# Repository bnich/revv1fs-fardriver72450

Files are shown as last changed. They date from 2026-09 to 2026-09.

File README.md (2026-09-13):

# FarDriver ND72450 under-seat mount — Ride1Up REVV1 FS

A pair of printed brackets that carry a **FarDriver ND72450** controller under the seat of a
**Ride1Up REVV1 FS**, bolting to the frame's existing rail lugs. No frame modification, no drilling,
no welding.

**Printed and in service.**

<p align="center">
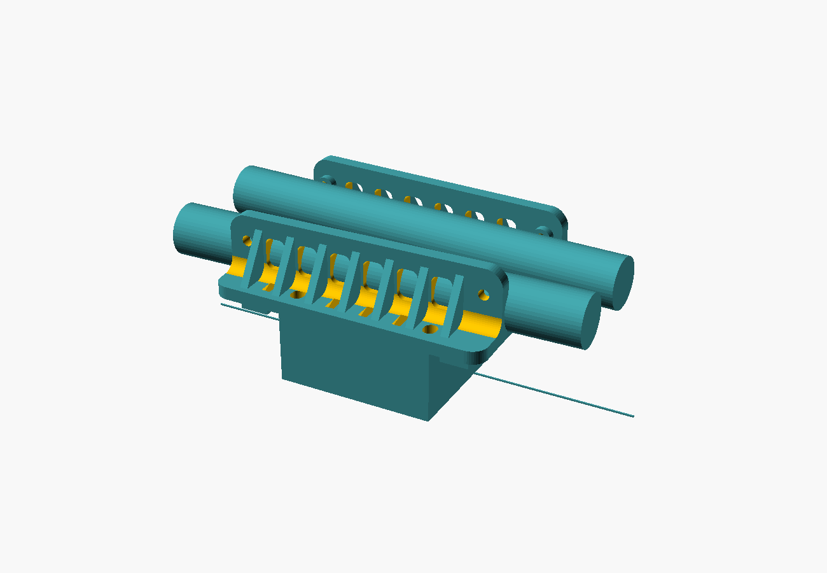
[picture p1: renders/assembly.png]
Isometric render of the pair of brackets spanning both frame rails, with the FarDriver controller slung beneath, showing the ribbed shelves and louvred vertical panels
  
</p>

The controller sits centred across the bike, spanning both rails and bolted to both brackets. Each
bracket carries roughly half the weight close in to its own rail, and the load is carried mostly in
**shear** rather than as a moment.

---

## What you get

| Part | Size | |
|---|---|---|
| `bracket_left` | 215 × 50.3 × 55 mm | one per rail |
| `bracket_right` | 215 × 50.3 × 55 mm | ⚠️ **a mirror image, not the same part again** |
| `brackets_plate` | 215 × 118 × 50.3 mm | both, laid down on one plate |
| `gauge` | 219.5 × 44 × 4 mm | print this **first** — see below |

<p align="center">
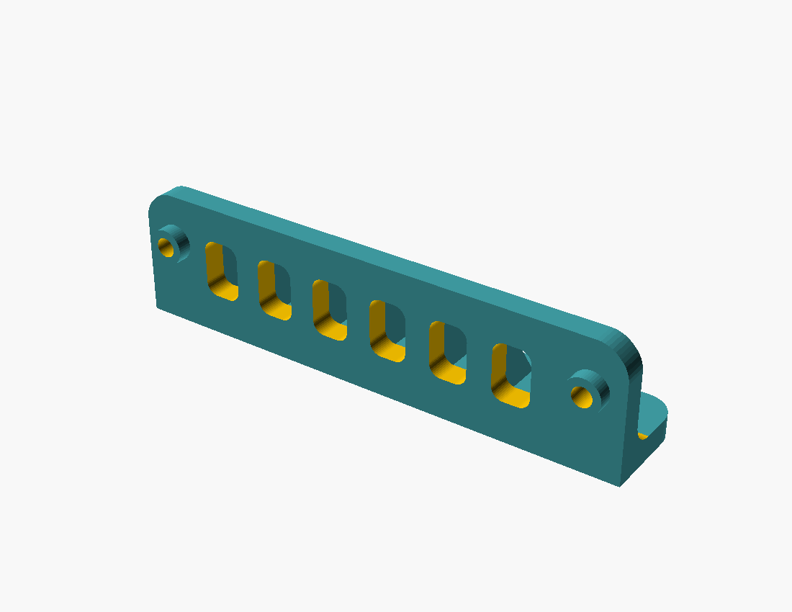
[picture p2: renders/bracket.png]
Single bracket: louvred vertical panel with two frame bolt holes at each end and the ribbed shelf projecting from its lower edge
  
</p>

---

## ⚠️ Read this before you print anything

These four are load-bearing. The bracket carries a **2.15 kg** controller over rough ground.

1. **ASA, PC, PETG-CF or PA-CF. NEVER PLA.** PLA creeps under sustained load and softens near 60 °C —
   which an under-seat cavity on a dark bike reaches in summer. This is not a preference.
2. **Metal compression limiters in every bolt hole**, so no bolt preload ever passes through plastic.
   M5 frame side, M6 controller side. **Never thread a bolt into the plastic** — a thread cut in ASA
   under a hanging load creeps and backs out.
3. **Print with the vertical panel flat on the bed**, shelf standing up.
4. **Proof-load it before you trust it.**

---

## Start here: print the fit gauge

The whole design hangs off one number — the **187 mm** spacing between the frame's two rail lugs. The
gauge is a thin plate with both holes and a tick scale. It costs a few grams and settles the question
on your own frame.

```bash
openscad -o stl/gauge.stl -D 'part="gauge"' src/fardriver-underseat-mount.scad
```

The gauge should slide over both lugs without force. If it feels tight on your frame, open **one**
hole with a 6 mm drill rather than reprinting — but only one, or the fore/aft datum starts to float.

⚠️ Lug spacing is measured on one frame. Frame dimensions vary between production runs, so confirm it
on yours before printing a 215 mm part.

---

## Documentation

| | |
|---|---|
| **[docs/geometry.md](docs/geometry.md)** | Frame rails, controller hole pattern, and every dimension the model uses |
| **[docs/design-notes.md](docs/design-notes.md)** | The design constraints, and what each one protects |
| **[docs/printing.md](docs/printing.md)** | Material, orientation, settings |
| **[docs/assembly.md](docs/assembly.md)** | Hardware, limiters, bolt stacks, order, proof-loading |

## Layout

```
src/      fardriver-underseat-mount.scad  — the whole model, one file
stl/      pre-built exports
renders/  preview images
docs/     the four documents above
tools/    build.sh · check_stl.py
```

## Building from source

Needs [OpenSCAD](https://openscad.org/) (developed against 2021.01) and Python 3.

```bash
./tools/build.sh
```

Individual parts:

```bash
openscad -o out.stl -D 'part="bracket_left"' src/fardriver-underseat-mount.scad
```

Parts: `bracket_left` · `bracket_right` · `plate` · `gauge` · `panel` · `layout` · `mock` · `section`
· `rig` · `jig_spine` · `jig_spine_pair` · `jig_carrier`.

The jigs and the rig are measuring aids used to derive the frame geometry in the first place. You do
not need them to print the mount, but they are there if you are adapting this to another frame.

---

## Adapting it to a different frame or controller

The model is parametric. The numbers you would change first:

```openscad
lug_spacing   = 187;   // between your frame's rail lug centres
lug_od        = 16;    // lug outside diameter
lug_standoff  = 6;     // ⚠ nothing bolts FLAT to this frame — see design notes
ctrl_hole_dx  = 106;   // controller hole pattern, ALONG the bike
ctrl_hole_dy  = 168;   // ACROSS the bike
drop          = 35;    // how far the controller hangs below the lug line
```

⚠️ **`ctrl_hole_dx` / `dy` are the trap.** On this build the controller's **long axis runs across the
bike**, so the pair of holes landing on any one bracket is the **106 mm** pair, not the 168 mm pair.
Get that backwards and the bracket is 60 mm too short in the wrong direction.

---

## Contributing

Issues and pull requests welcome — especially **lug-spacing measurements from other REVV1 FS frames**
and **photos of it fitted**. See [CONTRIBUTING.md](CONTRIBUTING.md).

## Licence

[CC BY-SA 4.0](LICENSE). Print it, modify it, sell prints of it — credit the source and share your
changes under the same terms.

## Disclaimer

This hangs 2.15 kg of controller under the seat of a moving vehicle, at 5 kW, over rough ground.
Nothing here has been tested to any standard. **Proof-load it, use the metal limiters, and re-check
every fastener after the first ride.** You are responsible for what you bolt to your own bike.

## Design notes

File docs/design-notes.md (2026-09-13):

# Design constraints

What the design requires and why, for anyone modifying the model or adapting it to another frame.
Each of these is load-bearing — changing it without understanding what it protects produces a part
that looks right and does not work.

---

## Two brackets, spanning both rails

The controller sits centred across the bike, bolted to a bracket on each rail. It is not cantilevered
off one.

Each bracket carries roughly half the weight close in to its own rail, and the load is carried mostly
in **shear** rather than as a moment trying to rotate a bracket about its bolt line.

⚠️ **The two brackets are mirror images, not the same part twice.** The shelf is a trapezoid, deeper
at the rear because the rails narrow going back, and the controller sits 9.5 mm rearward — so the
bracket is asymmetric front to back. Turning one end for end puts the deep end at the front.

They are mirrored in **X**, not Y. Both give the opposite hand, but mirroring in X keeps the pads and
the shelf on the same faces, so one lay-down rotation serves both parts on the print plate.

---

## Nothing bolts flat to this frame

The rail lug is recessed and the frame around it is a rounded tube. A bracket with a flat back face
fouls the tube before it reaches the lug face.

Every part bolting to these lugs stands off on a **washer-shaped pad at each hole** and touches the
frame nowhere else. The stack is:

```
frame lug → 2 mm side panel → 6 mm pad → bracket wall
```

⚠️ **The 6 mm pad height is measured against bare frame, panels off.** The bike's side panel goes
*under* the pad and **adds** to the stack — it does not substitute for part of it. With panels
fitted, the frame bolts are 2 mm longer. Limiter length is unchanged at 16 mm.

**If the bracket touches the tube anywhere, the pad height is wrong for your frame.** Do not force it.

---

## Ribs straddle the controller bolts

Rib pitch is a quarter of the controller bolt spacing (26.5 mm), **offset by half a pitch**, so each
bolt sits in the centre of a bay with a rib 13.25 mm either side.

⚠️ **Do not re-pitch the ribs to land on the bolts.** The nut goes on **top** of the shelf, and a rib
standing on the hole leaves no room for a nut or a socket. The offset gives **20.5 mm of clear width
at every bolt** — enough for a 10 mm socket — and the load still enters between two ribs a short
distance from both.

Rib positions are keyed to the controller bolts, not spaced evenly along the blank. Even spacing puts
ribs over vent slots and leaves the two points where load actually enters the shelf supported by
whatever happens to be nearby.

---

## Compression limiters in every bolt hole

Metal limiters everywhere, so the nut clamps **metal to metal** down the whole length and the plastic
never sits in the squeeze path. M5 frame side, M6 controller side.

⚠️ **Never thread a bolt directly into the plastic.** A thread cut in ASA under a hanging load creeps
and backs out. Heat-set brass inserts are acceptable on the controller side; a through-bolt with a
nyloc is stronger and cheaper.

The controller's four holes are **plain Ø7 through holes**, not threads, so the bolt must be captured
by the bracket:

```
bolt head + washer  under the controller's plate
  ↑ through the controller's Ø7 hole
  ↑ through the metal limiter in the standoff boss and the shelf
washer + NYLOC      on top of the shelf
```

⚠️ The shelf's hole is **10.2 mm** because it is the pocket for a **10 mm OD limiter tube**, not a
bolt hole. The bolt inside it is M6. Set `ctrl_limiter` to 6.6 if you would rather skip the tube and
spread the load with 20 mm washers, but the tube is the better joint.

---

## Shelf depth

**15 mm of material beyond the controller bolt centre** — what an M6 through a 10.2 mm limiter needs.

`shelf_margin` is a structural dimension and is defined as one. Do not tie it to the vent pattern:
a decision about where louvres may sit must not set how far the bracket overhangs the controller.

---

## Airflow

The shelf stands the controller off so air runs fore-and-aft along its alloy baseplate. Fore-and-aft
grooves in the shelf's underside run the same way.

The vertical panel carries **louvres rather than plain holes**, because plastic needs its section: a
louvre opens area for airflow while leaving more material in the load path than a round hole of the
same open area.

Engraved styling is engraved, not cut through, for the same reason.

---

## Known rough edges

For anyone working on the model:

- **The `part` selector falls through to `bracket()`.** An unrecognised or misspelt part name silently
  renders a bracket rather than failing, so you get a plausible STL of the wrong thing. A trailing
  `assert(false, ...)` is the fix.
- **There are no design assertions.** The constraints on this page are enforced by comments, not by
  `assert()`. Changing a number that breaks a relationship produces a part, not an error.
- **`reach_at()` interpolates linearly** between the front and rear rail spans. The rails are not
  necessarily linear between the two measured points; over 187 mm the error is small, but it is an
  assumption.

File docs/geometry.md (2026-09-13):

# Geometry — frame, controller, and the printed bracket

Every dimension the model uses. All figures are measured on one frame and one controller unless
noted; confirm the frame-side numbers on your own bike before printing.

---

## 1. The frame side — Ride1Up REVV1 FS

| | mm | Provenance |
|---|---|---|
| Lug spacing | **187** | ⚠️ confirm on your frame with the gauge before printing |
| Lug outside diameter | **16** | measured (15.98) |
| Frame bolt | **M5** | through a metal limiter |
| Pad standoff | **6** | ⚠️ measured against **bare frame**, panels off — the side panel adds to this stack |
| Pad diameter | **15** | sized to sit on the lug |
| Side panel | **2** | sits between frame and pad; **adds** to the stack |
| Lug face → bracket wall | **8** | = 6 + 2 |
| Limiter bore | **8.2** | pocket; cut the tube to **16 mm** = wall + standoff |

⚠️ **Nothing bolts flat to this frame.** The lug is recessed and the frame around it is a rounded
tube, so the bracket stands off on a pad at each hole and touches the frame nowhere else.

---

## 2. The controller — FarDriver ND72450

| | mm | |
|---|---|---|
| Baseplate | **120 × 180** | |
| Hole inset | **7** from the long edges, **6** from the ends | |
| Hole pattern | **106 × 168** | 120 − 2×7 = 106 · 180 − 2×6 = 168 |
| Controller holes | **Ø7 plain through holes** | ⚠️ **not threads** |
| Mass | **2.15 kg** | |
| Controller bolt | **M6 × 30** | through a 10.2 mm limiter pocket, nyloc on top of the shelf |
| Slot elongation | **±1.0** | outboard, so the pair can find the rails |

⚠️ **Orientation is the trap.** The controller's **long axis runs across the bike**, spanning between
the rails. So the pair of holes landing on any one bracket is the **106 mm** pair, not the 168 mm
pair. Read `dx` as *along* the bike and `dy` as *across* it.

---

## 3. The printed bracket, as it comes out

```
215 × 50.3 × 55 mm      wall 10 mm      7 ribs
```

| | mm | |
|---|---|---|
| Blank length | **215** | lug spacing + nose + tail |
| Panel thickness | **10** | plastic needs its section; this is not a sheet-metal bracket |
| Drop below lug line | **35** | |
| Margin above lugs | **20** | |
| End margin | **14** | |
| Rib pitch | **26.5** | = controller hole spacing ÷ 4, offset half a pitch so ribs straddle the bolts |
| Shelf margin | **15** | material kept beyond the **bolt centre** |

The rear controller bolt sits **31 mm behind the rear lug** — the shock clearance pushes the
controller rearward past it — so the blank grows a tail at that end to keep the bolt's standoff boss
landing on material.

---

## 4. Fasteners, summarised

| Where | Bolt | Through | Captured by |
|---|---|---|---|
| Frame | **M5** | 8.2 mm limiter, 16 mm long | frame lug |
| Controller | **M6 × 30** | 10.2 mm limiter in the shelf | washer + **nyloc on top of the shelf** |

⚠️ Different fasteners on the two sides. **Do not mix them.**

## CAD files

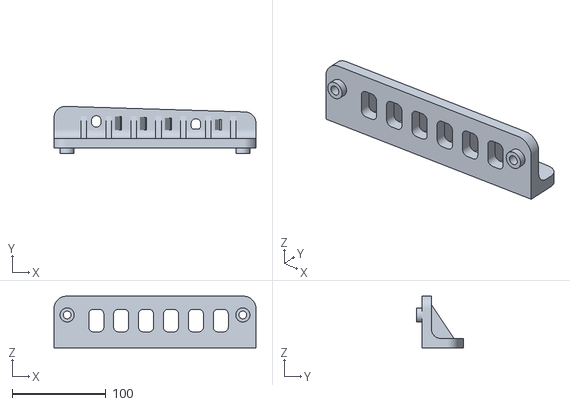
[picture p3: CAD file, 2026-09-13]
stl/bracket_right.stl
215.0 x 50.3 x 55.0

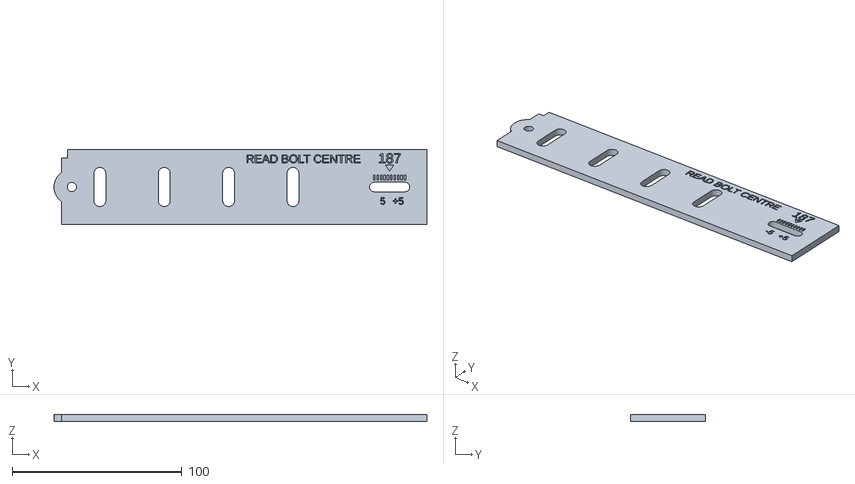
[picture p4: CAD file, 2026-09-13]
stl/gauge.stl
219.5 x 44.0 x 4.00

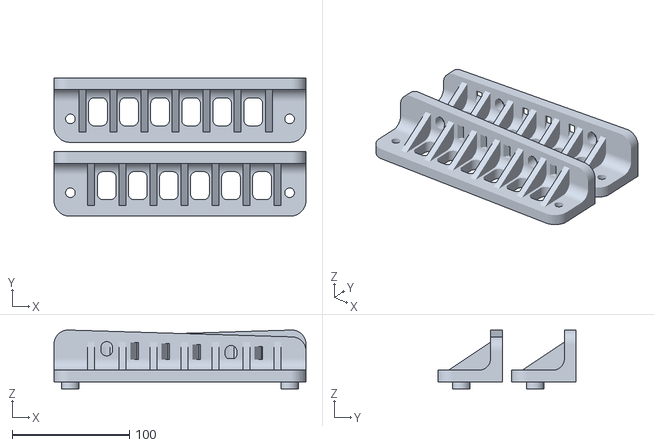
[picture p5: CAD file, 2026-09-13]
stl/brackets_plate.stl
215.0 x 118.0 x 50.3

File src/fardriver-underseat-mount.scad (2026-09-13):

// ============================================================
//  REVV1 · FarDriver ND72450 mount — PAIR OF PRINTED BRACKETS  (rev E)
//
//  CORRECTED 2026-09-07 (owner): there are TWO brackets, one on each frame
//  rail, and the controller bolts to BOTH. It sits centred across the bike,
//  spanning the two rails and protruding an equal amount past each — which is
//  what "the 12 cm side faces out and it is symmetrical" meant.
//
//  THIS IS STRUCTURALLY MUCH BETTER AND IT CHANGES THE WARNINGS:
//  the controller is no longer cantilevered off one rail. It is supported on
//  both sides, so the load is shared and carried mostly in SHEAR rather than as
//  a moment trying to rotate a single bracket about its bolt line. The earlier
//  worry about preload friction holding a cantilever largely goes away. Each
//  bracket now carries roughly half the weight, close in to its own rail.
//
//  Each bracket takes TWO of the controller's four holes — the pair on its side,
//  186 mm... no: 168 mm apart along the bike. The other two go to its mirror.
//
//  ⬜ GATING MEASUREMENT: the across-the-bike distance between the two rails'
//  LUG FACES (rail_face_span below). Everything about how far each shelf has to
//  reach falls out of that one number, and it is the last thing missing.
//
//  Unchanged from the earlier revisions and still true:
//    · ASA / PC / PETG-CF / PA-CF. NEVER PLA — it creeps and softens near 60 C.
//    · METAL COMPRESSION LIMITERS in every bolt hole, so no bolt preload ever
//      passes through plastic. Frame side M5, controller side M6.
//    · Controller bolts are M6 through its plain 7 mm holes, with a washer and
//      NYLOC on top of the shelf. Never thread into the plastic.
//    · Print with the VERTICAL PANEL FLAT ON THE BED, shelf standing up.
//    · The shelf stands off the controller so air runs fore-and-aft along the
//      alloy plate; louvres let the warmed air out.
//    · Proof-load before trusting it.
//
//  PARTS: gauge | panel | bracket | layout        (print bracket TWICE, mirrored)
// ============================================================


/* [MEASURED on the bike] */
/* ⚠ 187, NOT 186. The 2nd gauge read put it at 186 and the owner set that, but
   the printed spine at 186 only just went on over both lugs (owner 2026-09-07).
   A plate with two 5.5 mm holes swallows about half a millimetre of spacing error
   before it binds, so a "barely fits" is real evidence the true figure is nearer
   187. A fit test on a 4 mm plate beats a read off a tick scale, so 187 wins and
   this is now the canonical number for the brackets too.
   If 187 still feels tight, open ONE hole with a 6 mm drill rather than reprint —
   but only one, or the fore/aft datum starts to float. */
lug_spacing   = 187;
bolt_dia      = 5;
lug_od        = 16;

/* [FRAME-SIDE STANDOFF — owner 2026-09-07] ⚠ NOTHING BOLTS FLAT TO THIS FRAME.
   The lug is slightly RECESSED and the frame around it is a rounded tube, so a
   flat back face fouls the tube before the lug face is reached. Every part that
   bolts to these lugs therefore stands off on a washer-shaped pad at each hole
   and touches the frame NOWHERE else. This reverses the earlier "back face bears
   flat on the rail" assumption — that surface does not exist. */
/* Pad height, 6 mm. ⚠ I cut this to 4 once, reasoning the panel supplied 2 mm of the
   clearance. WRONG, and the owner caught it: every measurement was taken with the
   panels OFF, so the 6 mm the rounded frame needs is measured against bare frame and
   the panel does not come out of it. The panel goes UNDER the pad and adds to the
   stack rather than substituting for part of it.
   Order is: frame lug -> 2 mm panel -> 6 mm pad -> bracket wall. */
lug_standoff  = 6;
lug_pad_d     = 15;    // pad diameter, sized to sit on the lug (OD 15.98)
/* A 2 mm panel on each side sits between the frame and the bracket, and the bracket
   bears on it (owner 2026-09-08). It is part of the bike, not printed, so it is not
   modelled — but it pushes the whole bracket 2 mm further outboard, so every
   distance quoted from the LUG FACE has to cross it. ⚠ The frame bolts also get
   2 mm longer. Limiter length is unchanged at pad + wall = 16 mm. */
side_panel    = 2;
mount_off     = lug_standoff + side_panel;   // lug face to the bracket's inner wall

/* [CONTROLLER SIDE — a DIFFERENT fastener from the frame side, do not mix them]
   The FarDriver's four holes are PLAIN THROUGH HOLES at 7 mm (owner 2026-09-07),
   not threads. So they are clearance holes for an M6, and the bolt has to be
   captured by the bracket rather than by the controller.

   ⚠ DO NOT THREAD STRAIGHT INTO THE PLASTIC. A thread cut in ASA under a
   hanging load creeps and backs out. Assemble it this way instead:

       bolt head + washer under the controller's plate
         -> up through the controller's 7 mm hole
         -> up through the METAL LIMITER in the standoff boss and the shelf
         -> washer + NYLOC nut on top of the shelf

   The limiter means the nut clamps metal-to-metal down the whole length and the
   plastic never sits in the squeeze path, same principle as the frame side. The
   solid disc the vent mask leaves round each hole is the washer face. Heat-set
   brass inserts are an acceptable alternative, but a through-bolt with a nyloc
   is stronger and cheaper. */
/* [CONTROLLER FASTENER — M6 x 30, owner 2026-09-09]
   M6 passes the baseplate's 7 mm holes cleanly, so there is nothing to drill. It also
   restores the limiter on this side: 10 mm of shelf sits in the clamp path and a
   printed part will creep under a constant preload without a steel tube carrying it.
   ⚠ THIS IS WHY THE HOLE IS 10.2 AND NOT 6.6. The 10.2 is the pocket for a 10 mm OD
   limiter tube, not the bolt hole — the bolt inside it is 6 mm. Set ctrl_limiter to
   6.6 if you would rather skip the tube and spread the load with 20 mm washers, but
   the tube is the better joint. */
ctrl_bolt_dia = 6;     // M6 x 30
ctrl_limiter  = 10.2;  // pocket for a 10 mm OD limiter, cut to the 10 mm shelf
ctrl_slot     = 1.0;   // +/- outboard elongation. Was 1.5; trimmed now the across
                       // position is measured rather than derived, but not to zero:
                       // it still comes from the taped lug spans and the toe.

/* [CONTROLLER HOLE PATTERN — owner sketch 2026-09-07]
   ⚠ THE SKETCH LABELS THE OVERALL SIZES "12mm x 18mm". Read as CENTIMETRES:
   120 x 180 mm, which matches the ND72450 flat-plate spec. It cannot be
   millimetres — a 7 mm inset does not fit inside a 12 mm width, and no 12 x 18
   mm plate carries a 2.15 kg controller. The two small figures ARE millimetres:
   holes sit 7 mm in from the long edges and 6 mm in from the short ends.
      across the plate (120 wide):  7 .. 113  ->  106 mm apart
      along the plate (180 long):   6 .. 174  ->  168 mm apart

   ⚠ ORIENTATION, CORRECTED 2026-09-08 (owner). The controller does NOT bolt to a
   rail along its long edges. Its LONG axis runs ACROSS the bike, spanning between
   the two rails, so the pair of holes landing on any one bracket is the 106 mm
   pair, not the 168 mm pair. Everything below reads dx as ALONG the bike and dy
   as ACROSS it, so the fix is simply which number goes where.

   This is not a detail. With 168 across, the hole row lands 36-46 mm outboard of
   the lug face, clear of the bracket's own 16 mm of standoff and wall. With 106
   across it landed 5-15 mm out, inside the bracket, which is why nothing would go
   together. It also pulls the rear bolt back in FRONT of the rear lug, so the
   bracket no longer needs a tail hanging off its end.
   ✅ CORROBORATED 2026-09-08, no longer just a sketch reading. The 168 figure is
   now checked against two independent measurements: the front lug span taped at
   105 predicts a front reach of (168 - 105)/2 = 31.50, and the rig read 32-33 there.
   Nothing but a value near 168 lands in that window — 160 would be 4.5 mm out and
   176 would be 3.5 mm out, against a rig that resolves to about 2 mm. The 106
   figure is corroborated by fit: the carrier's slots are cut 106 apart and the
   controller located in them. The pattern is settled. */
ctrl_hole_dx  = 106;   // ALONG the bike  (the plate's 120 mm width runs fore/aft)
ctrl_hole_dy  = 168;   // ACROSS the bike (the plate's 180 mm length spans the rails)
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

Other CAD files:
stl/bracket_left.stl

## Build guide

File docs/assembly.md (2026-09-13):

# Assembly

## Hardware

| Where | Part | Note |
|---|---|---|
| Frame | **2 × M5** per bracket | length = your frame's needs **+ 2 mm** if the side panels are on |
| Frame | **M5 compression limiters**, 8.2 mm OD | ⚠️ **cut to 16 mm** = 10 mm wall + 6 mm standoff |
| Controller | **4 × M6 × 30** socket cap | |
| Controller | **M6 limiters**, 10 mm OD | cut to the 10 mm shelf |
| Controller | **4 × M6 nyloc** + washers | nut goes **on top of** the shelf |

⚠️ **The two sides use different fasteners. Do not mix them.**

## ⚠️ Limiters are mandatory

Every bolt hole takes a metal compression limiter so the nut clamps **metal to metal** down the whole
length and the plastic never sits in the squeeze path.

**Never thread a bolt into the plastic.** A thread cut in ASA under a hanging load creeps and backs
out. Heat-set brass inserts are an acceptable alternative on the controller side; a through-bolt with
a nyloc is stronger and cheaper.

If you skip the limiters, the joint will feel fine on the bench and loosen on the road.

## The controller bolt stack

The controller's own holes are **plain Ø7 through holes**, not threads, so the bolt is captured by
the bracket:

```
bolt head + washer  under the controller's plate
  ↑ through the controller's Ø7 hole
  ↑ through the metal limiter in the shelf
washer + NYLOC      on top of the shelf
```

⚠️ The shelf's hole is **10.2 mm** because that is the *pocket for a 10 mm limiter tube* — not a
10 mm bolt. The bolt inside it is M6.

## Order

1. **Gauge first** — confirm 187 mm on your frame before anything else.
2. **Frame limiters into both brackets**, then bracket to rail. Pads bear on the lugs; **the bracket
   should touch the frame nowhere else.** If it contacts the tube, stop — the pad height is wrong for
   your frame, not the bolts.
3. **Snug, do not torque yet.** The second frame hole is elongated along the rail so the pair can find
   the lugs.
4. **Controller up to the shelves**, four M6 × 30 through the limiters, nyloc on top.
5. **Now torque everything**, working across rather than around.
6. **Proof-load.** Hang on it. Shake it hard. Do this on the bench, not on the first ride.

## Before you ride

- ⚠️ **Check shock clearance through full travel.** The controller sits rearward specifically to clear
  the shock; confirm it on your bike rather than trusting the model.
- **Re-check every fastener after the first ride.** A paint witness line across each nut and the shelf
  makes movement visible at a glance.
- Check the phase and battery leads are not strained or rubbing at full suspension travel.

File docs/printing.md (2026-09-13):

# Printing

## Material

**ASA, PC, PETG-CF or PA-CF. NEVER PLA.**

This is not a preference. PLA creeps under sustained load and softens near 60 °C, and the part hangs
2.15 kg in an under-seat cavity that reaches that in summer sun. A creeping bracket does not fail
suddenly — it sags, the bolts loosen, and then it fails.

ASA is the default here: it also holds up under UV. PETG-CF and PA-CF are both good choices if you
have them dialled in. PC if you have the enclosure.

## Orientation

**Print with the vertical panel flat on the bed, shelf standing up.**

That puts the layer lines across the panel rather than along the load path, and the shelf — which
carries the controller's weight in bending — prints as vertical walls rather than as a flat
cantilever that would peel layer from layer.

No supports are needed in this orientation. If your slicer wants them, the part is oriented wrong.

## Settings

- **Layer height** 0.2 mm.
- **Walls** 4 minimum. The 10 mm panel is thick, but its strength is in the perimeters.
- **Infill** 40–50 %. This is a structural part and a small one; do not economise here.
- **Brim** helps with ASA, which likes to lift.

## What to print, in order

1. **`gauge`** — settles the 187 mm lug spacing on your own frame. A few grams.
2. **`bracket_left`** and **`bracket_right`**, or **`plate`** for both at once.

⚠️ **`bracket_right` is a mirror image, not a second copy of `bracket_left`.** Printing the same part
twice gives you two left-hand brackets, and it is not obvious by eye — the shelf is a shallow
trapezoid. Use `plate` if you would rather not think about it.

## Building the STLs yourself

```bash
./tools/build.sh
```

> ⚠️ **If you script around OpenSCAD:** a failed `assert()` still exits 0 when exporting a tree format
> (`echo`, `csg`, `ast`, `term`) and for PNG, and only returns non-zero for a **solid** format
> (`stl`, `off`, `3mf`, `amf`). `build.sh` exports solid formats for that reason. Also,
> `openscad -o /dev/null` fails for any `.scad` file — `/dev/null` has no extension to infer a format
> from, so pass `--export-format=asciistl`.

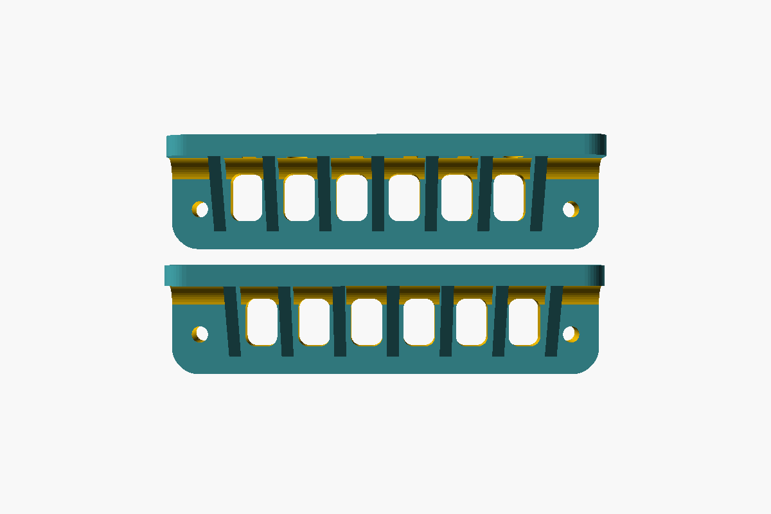
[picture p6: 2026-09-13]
renders/print-plate.png

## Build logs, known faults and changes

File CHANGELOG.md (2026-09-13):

# Changelog

## Unreleased

### Added
- First public release. Printed and in service.
- `bracket_left`, `bracket_right`, `brackets_plate` and the `gauge`, plus the measuring jigs and rig
  used to derive the frame geometry.
- Documentation: geometry, design constraints, printing and assembly.

### Known
- The `part` selector falls through to `bracket()` for an unrecognised name, so a typo silently
  renders a plausible STL of the wrong thing.
- The model has no `assert()` guards; its constraints are enforced by comments.

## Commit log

2026-09-13 Initial commit: printed under-seat mount for a FarDriver ND72450
    A pair of brackets carrying a FarDriver ND72450 under the seat of a
    Ride1Up REVV1 FS, bolting to the frame's existing rail lugs. No frame
    modification. This design is printed and in service; the bike runs on it.
    The controller spans both rails rather than cantilevering off one, so the
    load is shared and carried mostly in shear rather than as a moment trying
    to rotate a single bracket about its bolt line.
    Most of what is documented here is corrections, because the shape is
    largely the shape of the mistakes found on a real frame:
    - The lug spacing is 187, not the 186 a tick scale gave. A spine printed
    at 186 only just went o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
    [bracket_left.stl, bracket_right.stl, brackets_plate.stl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]
2026-09-13 docs: state the specification, not how it was arrived at
    Strip process narrative from the documentation. A reader needs the
    dimension and the constraint it protects, not the history of how the
    number was found.
    Kept where it changes what a reader does: that frame- and display-side
    figures are measured on one unit and should be confirmed; that a figure
    derived from the manual's side elevation runs optimistic; the known rough
    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
